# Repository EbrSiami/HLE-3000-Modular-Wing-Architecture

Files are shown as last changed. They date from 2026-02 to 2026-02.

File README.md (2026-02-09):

# SkyTitan (HLE-3000) Modular Wing Architecture





**MOIS, see? YOU FAILD!**

<div align="center">
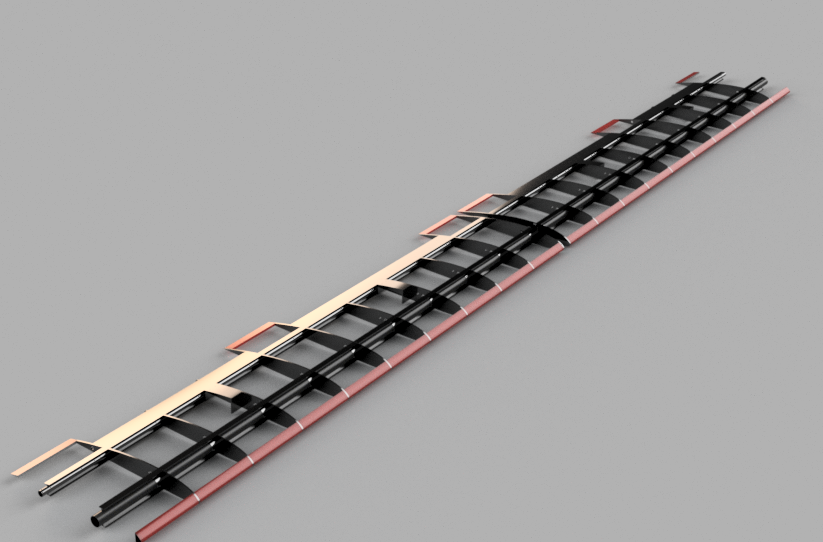
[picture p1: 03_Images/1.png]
  
</div>

## Overview
**SkyTitan (HLE-3000)** is a high-performance, modular fixed-wing UAV architecture designed for long-range surveying, aerial mapping, and endurance research missions. The design features a 3-meter wingspan with a **Clark-Y** airfoil, optimized for stability and high lift capacity.

This repository contains the STEP files for the 20-piece modular wing system, featuring a unique interlocking mechanism and a specialized **Slotted Flap** system for superior STOL (Short Take-Off and Landing) capabilities.

> **Design Goal:** To create a cost-effective, printable airframe capable of carrying up to 3kg of payload with a flight endurance of 300-400km (using a 52cc gas engine).

## Technical Specifications

| Parameter | Value |
| :--- | :--- |
| **Wingspan** | 3000 mm (3 Meters) |
| **Chord Length** | 350 mm |
| **Airfoil** | Clark-Y |
| **Construction** | 3D Printed (Modular - 20 Sections) |
| **Est. Wing Weight** | ~1260g (PETG Printed) |
| **Max T.O. Weight (MTOW)** | Up to 15 kg |
| **Payload Capacity** | ~3 kg |
| **Propulsion** | 50cc - 55cc Gas Engine (Recommended) |

## Key Features
*   **Modular Design:** The wing is divided into 20 sections (10 Left / 10 Right) connected via a robust male/female interlocking interface.
*   **Advanced Control Surfaces:** Features a **Slotted Flap** mechanism for high-lift performance during landing and takeoff.
*   **Integrated Avionics Bays:** Dedicated compartments for servos, wiring, and internal antenna placement to reduce drag.
*   **Structural Integrity:** Reinforced with dual carbon fiber spars (Main & Rear).
*   **Cost-Effective:** Designed to be printed with standard FDM printers using PETG or PLA.

## Bill of Materials (BOM)

### Required Hardware
*   **Main Spar:** 20mm OD Carbon Fiber Tube.
*   **Rear Spar:** 10mm OD Carbon Fiber Tube.
*   **Servos:** 4x Standard Size High-Torque Servos (e.g., MG996R, MG946, MG995 or stronger).
    *   2x Ailerons
    *   2x Flaps
*   **Connectors:** Heavy-duty aviation connectors (e.g., GX16 or Military spec) recommended for wing-to-body connection.
*   **Adhesive:** CA Glue (Thick) or High-grade Epoxy for joining sections.

## Printing Guide

### Material Recommendation
*   **Primary:** **PETG** (Highly recommended for gas engines due to vibration and heat resistance).
*   **Secondary:** **PLA+** (Acceptable for electric setups or lower loads).
*   **Not Recommended:** ABS (unless printed in a high-quality heated chamber due to warping risks on large parts).

### Slicer Settings
*   **Nozzle:** 0.4mm or 0.6mm
*   **Layer Height:** 0.2mm - 0.28mm
*   **Wall Line Count:** 2 (minimum)
*   **Infill:** 5% - 10% (Gyroid or Cubic recommended for strength/weight ratio)
*   **Supports:**
    *   **General:** No supports needed for most parts.
    *   **Exception:** The **Flap Hinge** sections require minimal supports (Tree Supports recommended).

## Assembly Notes
1.  **Mirroring:** The provided STEP files in the `STEP_Files` folder cover the entire wing (Left & Right). If using the CAD source for modifications, please mirror the Right Wing assembly for the Left side.
2.  **Reinforcement:** Ensure carbon tubes fit snugly. Glue all interlocking sections generously to withstand engine vibrations.
3.  **Wiring:** Route servo cables and antenna wires through the pre-designed internal channels before gluing the final sections.

## Gallery & Details

<div align="center">
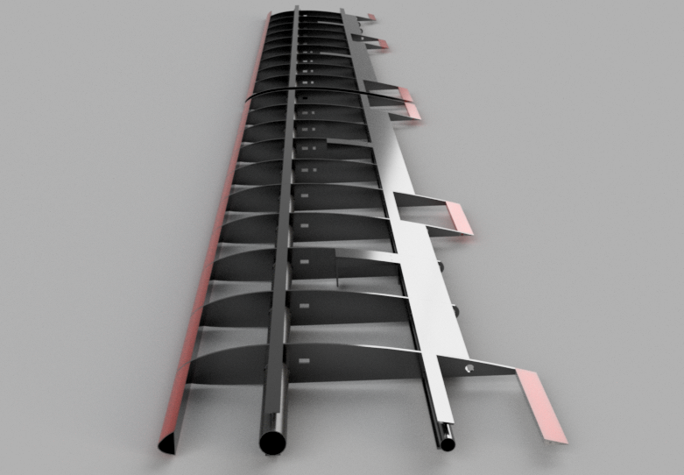
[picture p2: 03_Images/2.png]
  
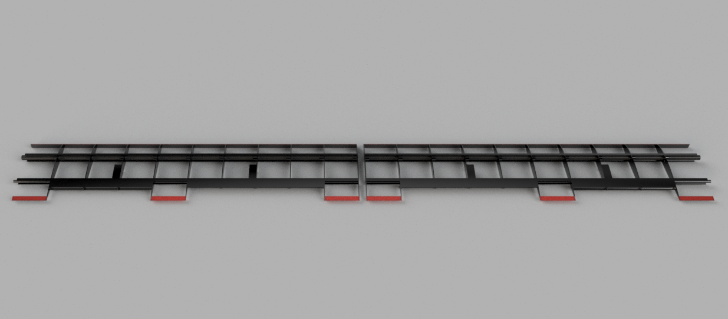
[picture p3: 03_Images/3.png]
  
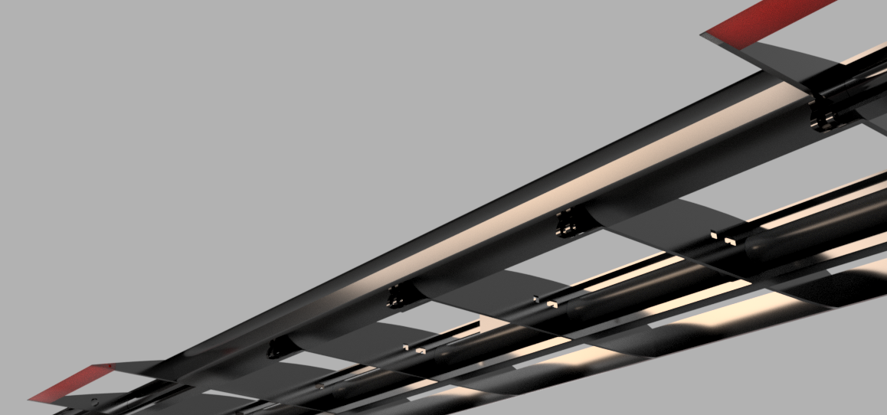
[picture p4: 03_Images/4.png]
  
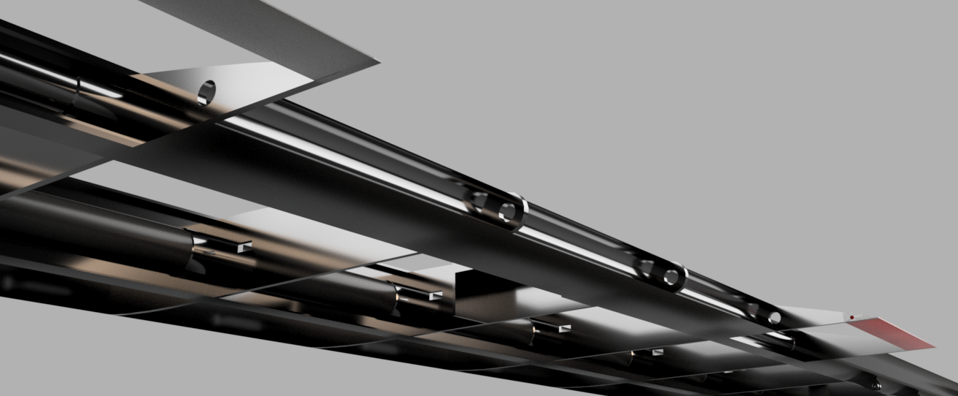
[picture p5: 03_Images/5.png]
  
  <br/>

</div>

## ⚠️ Legal Disclaimer & Safety Warning

**PLEASE READ CAREFULLY:**

This project is shared for **Educational, Research, and Non-Commercial purposes only**.

1.  **Compliance:** The user is solely responsible for complying with all local, state, and international aviation regulations regarding Unmanned Aerial Vehicles (UAVs), including but not limited to registration, weight limits, and flight zones (e.g., FAA in USA, EASA in Europe, CAO in Iran, etc.).
2.  **Liability:** The designer/creator of these files accepts **NO responsibility** for any damage, injury, or legal issues arising from the construction, operation, or misuse of this design.
3.  **Nature of Design:** This aircraft is capable of long-range flight and high speeds. It is **NOT a toy**. Improper assembly or operation can result in serious injury or property damage.
4.  **License:** This work is licensed under a [Creative Commons Attribution-NonCommercial-ShareAlike 4.0 International License](http://creativecommons.org/licenses/by-nc-sa/4.0/). Commercial production or military use without explicit permission is strictly prohibited.

---
*Designed with passion for the open-source aerospace community.*

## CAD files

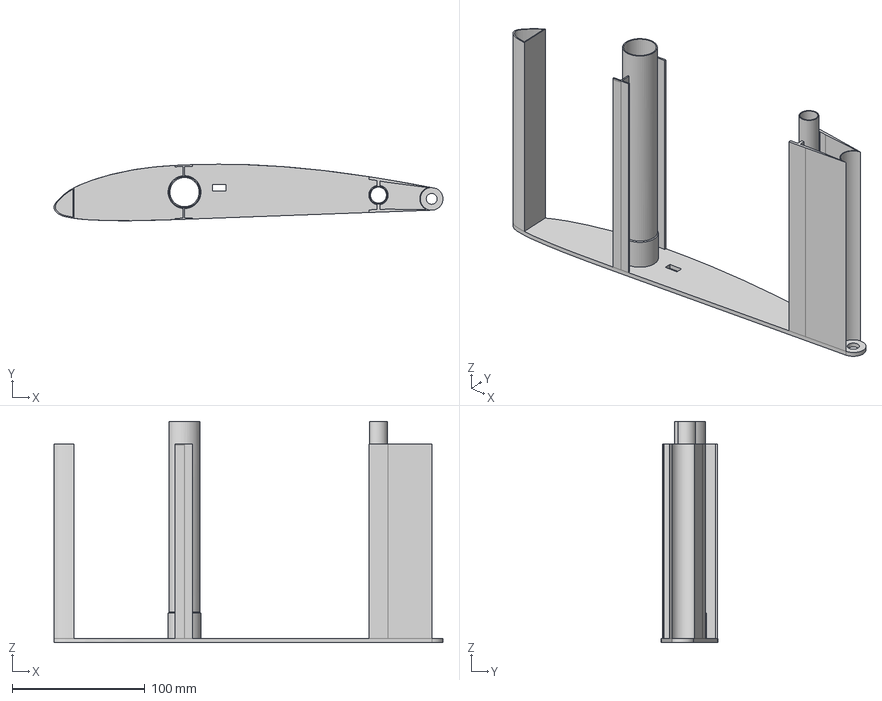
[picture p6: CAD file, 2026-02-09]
01_STEP_Files/Left_Wing/Wing_L_09_Aileron_End.step
293.5 x 42.7 x 167.0 mm

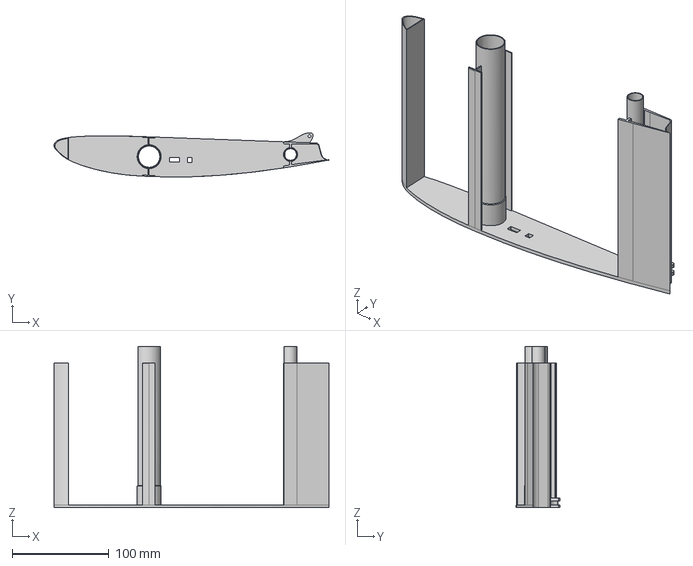
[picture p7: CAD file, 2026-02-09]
01_STEP_Files/Right_Wing/Wing_R_05_Flap_End.step
284.6 x 45.5 x 167.0 mm

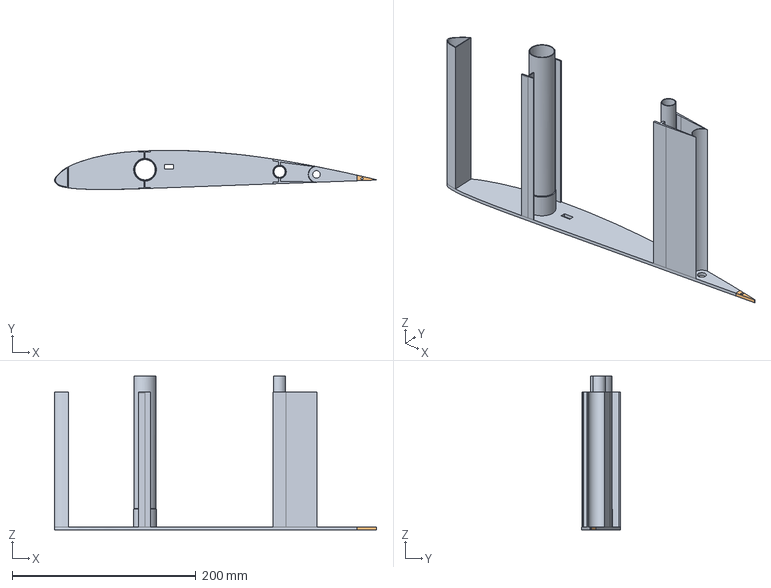
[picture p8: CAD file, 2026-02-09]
01_STEP_Files/Left_Wing/Wing_L_07_Aileron_Start.step
350.2 x 42.7 x 167.0 mm

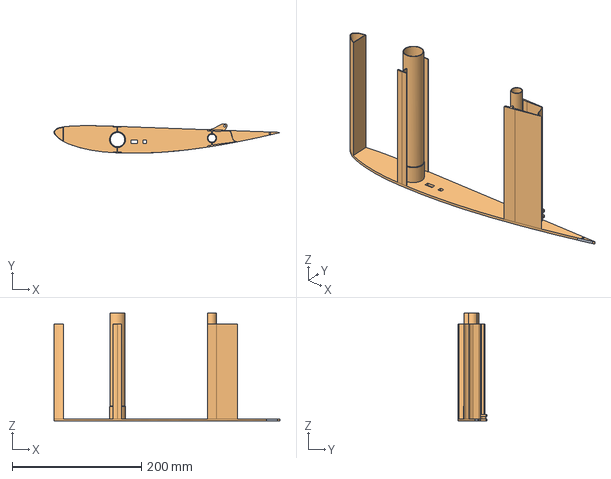
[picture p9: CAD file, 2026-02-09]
01_STEP_Files/Right_Wing/Wing_R_02_Flap_Start.step
350.2 x 45.5 x 167.0 mm

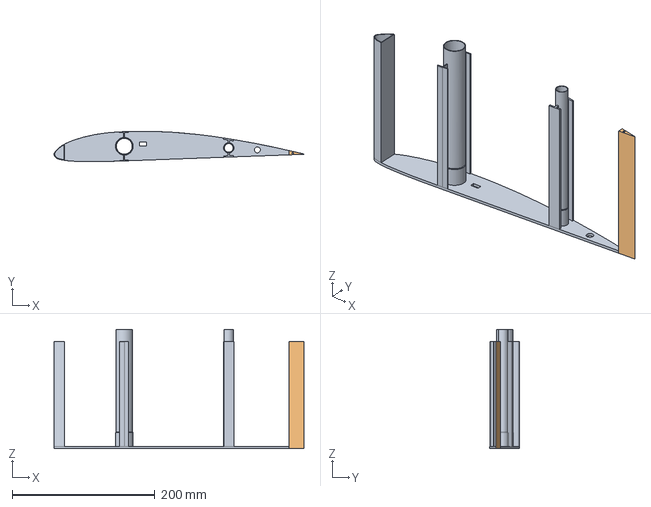
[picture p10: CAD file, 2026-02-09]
01_STEP_Files/Left_Wing/Wing_L_10_WingTip.step
350.2 x 42.7 x 167.0 mm

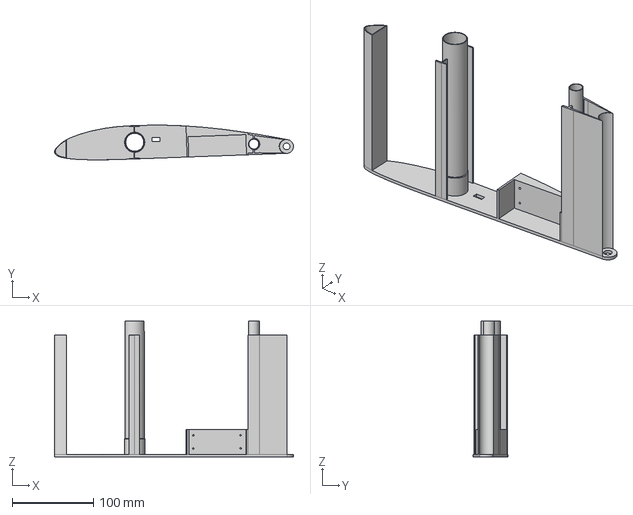
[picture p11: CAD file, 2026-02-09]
01_STEP_Files/Left_Wing/Wing_L_08_Aileron_ServoBay.step
293.5 x 42.7 x 167.0 mm

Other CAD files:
01_STEP_Files/Right_Wing/Wing_R_07_Aileron_Start.step
01_STEP_Files/Left_Wing/Wing_L_05_Flap_End.step
01_STEP_Files/Right_Wing/Wing_R_01_Root_Base.step
01_STEP_Files/Left_Wing/Wing_L_06_Transition_Solid.step
01_STEP_Files/Right_Wing/Wing_R_03_Flap_Mid.step
01_STEP_Files/Left_Wing/Wing_L_03_Flap_Mid.step
01_STEP_Files/Right_Wing/Wing_R_06_Transition_Solid.step
01_STEP_Files/Left_Wing/Wing_L_01_Root_Base.step
01_STEP_Files/Right_Wing/Wing_R_10_WingTip.step
01_STEP_Files/Right_Wing/Wing_R_09_Aileron_End.step
01_STEP_Files/Left_Wing/Wing_L_02_Flap_Start.step
01_STEP_Files/Right_Wing/Wing_R_04_Flap_ServoBay.step
01_STEP_Files/Left_Wing/Wing_L_04_Flap_ServoBay.step
01_STEP_Files/Right_Wing/Wing_R_08_Aileron_ServoBay.step
02_CAD_Source/Wing_L_01_Root_Base.f3d
02_CAD_Source/Wing_L_02_Flap_Start.f3d
02_CAD_Source/Wing_L_03_Flap_Mid.f3d
02_CAD_Source/Wing_L_04_Flap_ServoBay.f3d
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

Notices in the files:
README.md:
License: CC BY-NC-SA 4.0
